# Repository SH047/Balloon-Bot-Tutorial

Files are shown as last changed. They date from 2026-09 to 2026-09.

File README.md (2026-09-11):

# Balloon Bot

Bluetooth gamepad-controlled robot built with an ESP32, Bluepad32, an L298N dual H-bridge motor driver, and two DC drive motors.

This repository includes two controller modes, mechanical CAD files, original tutorial and demonstration videos, and a wiring reference covering the requested 1000 µF capacitor and independent 18650-powered auxiliary motor.

## Wiring diagram

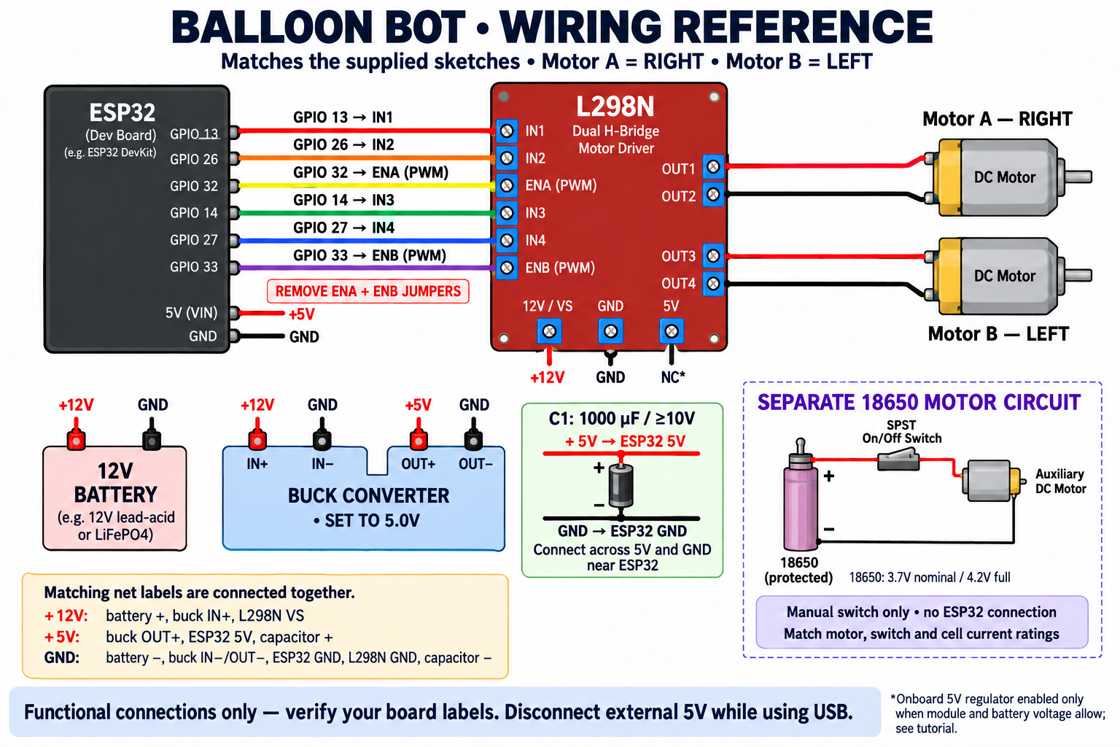
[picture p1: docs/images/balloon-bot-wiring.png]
Balloon Bot ESP32 and L298N wiring diagram


> [!IMPORTANT]
> The diagram and table follow the supplied sketches: **Motor A is the right motor** and **Motor B is the left motor**. Check the labels printed on your own ESP32 and L298N boards before applying power.

## ESP32 to L298N connections

| ESP32 pin | L298N pin | Function |
| --- | --- | --- |
| GPIO 13 | IN1 | Right motor direction 1 |
| GPIO 26 | IN2 | Right motor direction 2 |
| GPIO 32 | ENA | Right motor PWM / speed control |
| GPIO 14 | IN3 | Left motor direction 1 |
| GPIO 27 | IN4 | Left motor direction 2 |
| GPIO 33 | ENB | Left motor PWM / speed control |

Remove the black jumper caps from **ENA** and **ENB** before connecting GPIO 32 and GPIO 33. These enable pins receive PWM from the ESP32.

### Drive motors

- L298N `OUT1` and `OUT2` → right drive motor (Motor A)
- L298N `OUT3` and `OUT4` → left drive motor (Motor B)
- If a wheel turns in the wrong direction, disconnect power and swap that motor's two output wires.

## Main power wiring

Make every connection with the battery and USB cable disconnected.

| Source | Destination |
| --- | --- |
| 12V battery positive | L298N `12V / VS` and buck converter `IN+` |
| 12V battery negative | L298N `GND` and buck converter `IN−` |
| Buck converter `OUT+` set to 5.0V | ESP32 `5V / VIN` input, if supported by your board |
| Buck converter `OUT−` | ESP32 `GND` |
| ESP32 `GND` | L298N `GND` common ground |

The ESP32, L298N, buck converter, and main battery must share a common ground. Set and measure the buck converter output at **5.0V before connecting the ESP32**. Never connect the 12V battery directly to an ESP32 power pin, and never connect 5V to the ESP32 `3V3` pin.

The diagram leaves the L298N `5V` terminal disconnected. This assumes the module's separate `5V-EN` regulator jumper is fitted and the onboard regulator is compatible with the battery's fully charged voltage. L298N modules vary, so verify your module. Do not connect an enabled onboard 5V regulator output to the buck converter output.

## 1000 µF capacitor

Install a polarized **1000 µF electrolytic capacitor rated for 10V or higher** close to the ESP32:

```text
Buck OUT+ (5.0V) ────────┬──────── ESP32 5V
                         │ +
                    1000 µF
                     ≥ 10V
                         │ −
Buck OUT− (GND) ─────────┴──────── ESP32 GND
```

- Capacitor positive (`+`) → 5V
- Capacitor negative (`−`, normally marked with a stripe) → GND
- Connect it **in parallel across 5V and GND**, never in series.
- Keep the capacitor leads short.

## Separate 18650 motor circuit

The auxiliary motor is a separate manual circuit and has no connection to the ESP32 or L298N:

```text
Protected 18650 (+) ─── SPST on/off switch ─── Auxiliary motor (+)
Protected 18650 (−) ───────────────────────── Auxiliary motor (−)
```

Use a motor rated for a Li-ion cell's **3.7V nominal / 4.2V fully charged** voltage. The protected cell, holder, switch, and wiring must safely carry the motor's starting and stall current. Charge the cell only with a suitable Li-ion charger.

## Controller modes

### Single-stick arcade control

[SingleStickctrl.ino](SingleStickctrl/SingleStickctrl.ino) uses the left stick for throttle and steering, mixing both values into left- and right-wheel commands.

### Two-stick tank control

[TankdrvCtrl.ino](TankdrvCtrl/TankdrvCtrl.ino) uses the right stick for Motor A/right and the left stick for Motor B/left.

Both sketches use a deadzone and capped PWM output. Read the documented [failsafe limitation](docs/TUTORIAL.md#code-behavior-and-limitation) before testing.

## Arduino setup

1. Install [Arduino IDE](https://www.arduino.cc/en/software).
2. Follow the [Bluepad32 Arduino setup guide](https://bluepad32.readthedocs.io/en/latest/plat_arduino/).
3. Install the ESP32 and ESP32 + Bluepad32 board packages.
4. Select your compatible original ESP32 board under **Tools → Board → ESP32 + Bluepad32 Arduino**.
5. Open one controller sketch, select the USB port, and upload it.
6. Open Serial Monitor at **115200 baud** and pair the controller.

For PS4/PS5-style controllers that use Bluetooth Classic, use an original ESP32 such as an ESP32-WROOM-32 board. ESP32-S3 and ESP32-C3 boards do not provide Bluetooth Classic.

## Videos

- [Code training tutorial](videos/Ballon%20bot%20Code%20training%20.mov)
- [Balloon Bot demonstration](videos/Demo%20Ballon%20bot%20.mp4)
- [Download both original recordings from the GitHub release](https://github.com/SH047/Balloon-Bot-Tutorial/releases/tag/videos-v1)

## Repository contents

```text
Balloon-Bot-Tutorial/
├── SingleStickctrl/       Single-stick arcade control sketch
├── TankdrvCtrl/           Two-stick tank control sketch
├── Ballon BotCAD /        STL and DXF mechanical parts
├── docs/                  Full tutorial, validation, and wiring assets
├── videos/                Original tutorial and demonstration recordings
└── README.md              Project overview and wiring guide
```

## Documentation

Both sketches compile successfully against the ESP32 + Bluepad32 board package. See [VALIDATION.md](docs/VALIDATION.md) for recorded checks and [TUTORIAL.md](docs/TUTORIAL.md) for detailed assembly, testing, troubleshooting, and safety notes.

## Author

Created by [Shreyas S Rai](https://github.com/SH047).

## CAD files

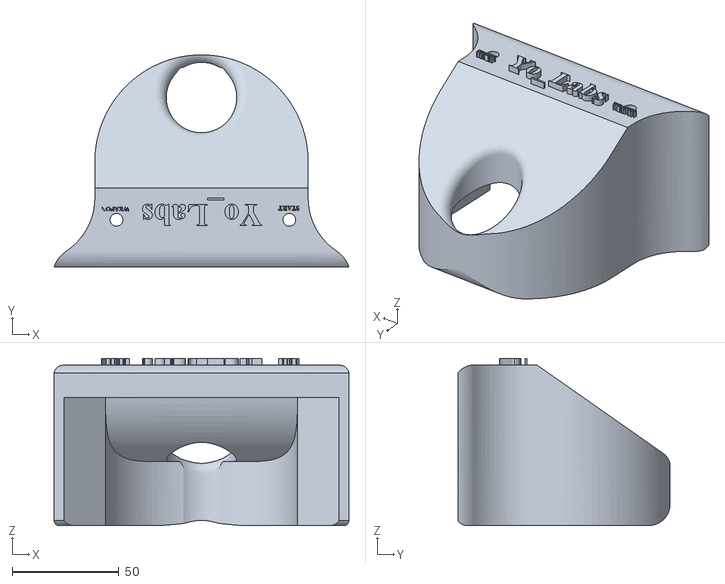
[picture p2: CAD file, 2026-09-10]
Ballon BotCAD /RED Ballon Front.stl
138.3 x 99.5 x 78.3

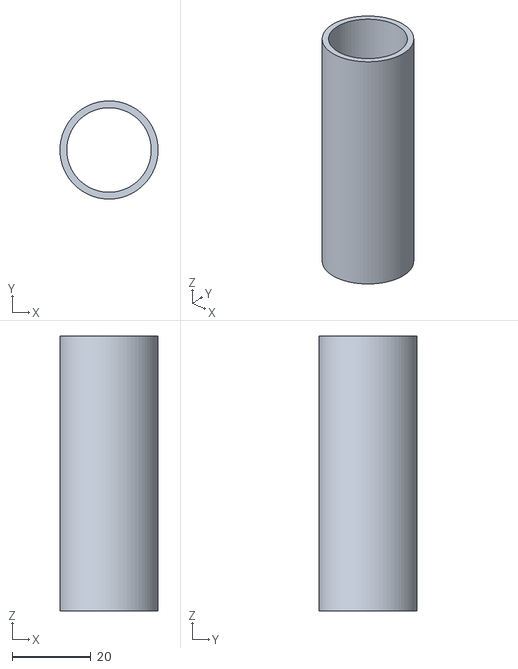
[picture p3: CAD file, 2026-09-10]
Ballon BotCAD /pvc 70 mm.stl
25.0 x 25.0 x 70.0

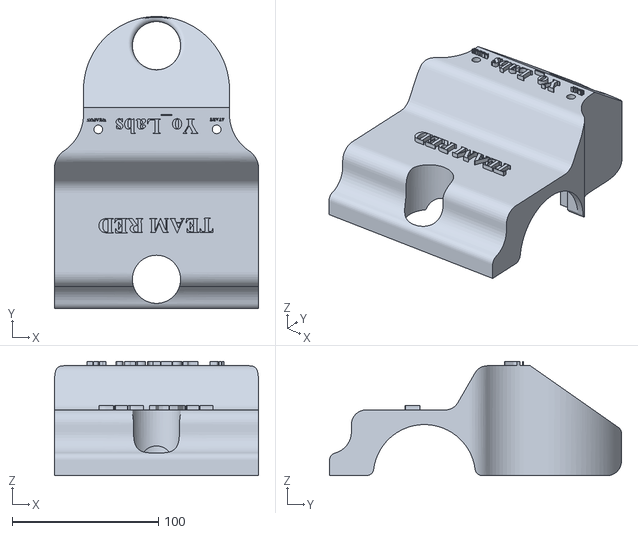
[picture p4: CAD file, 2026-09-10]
Ballon BotCAD /RED TEam Ballon.stl
140.0 x 200.0 x 78.3

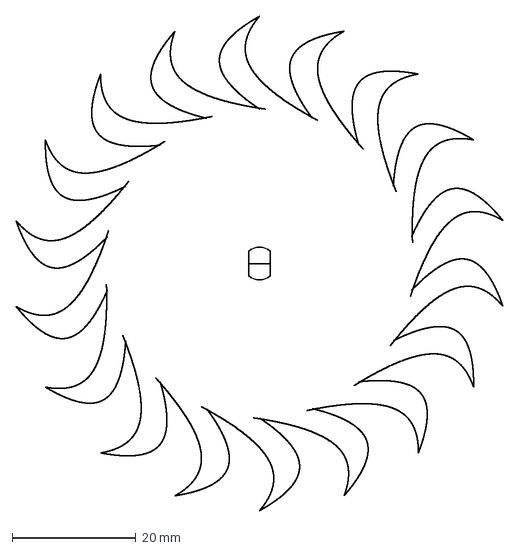
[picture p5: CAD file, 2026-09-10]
Ballon BotCAD /Spin blade V2 Harvest.dxf
78.8 x 80.0 mm

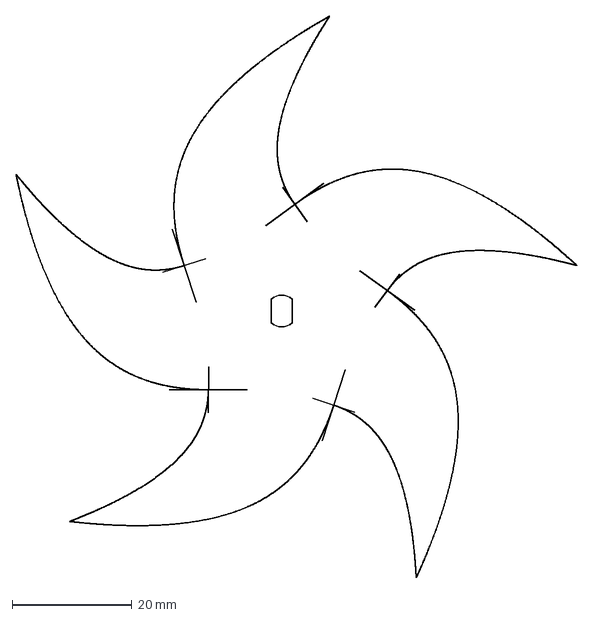
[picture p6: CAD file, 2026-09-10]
Ballon BotCAD /Saw2.dxf
93.9 x 94.0 mm

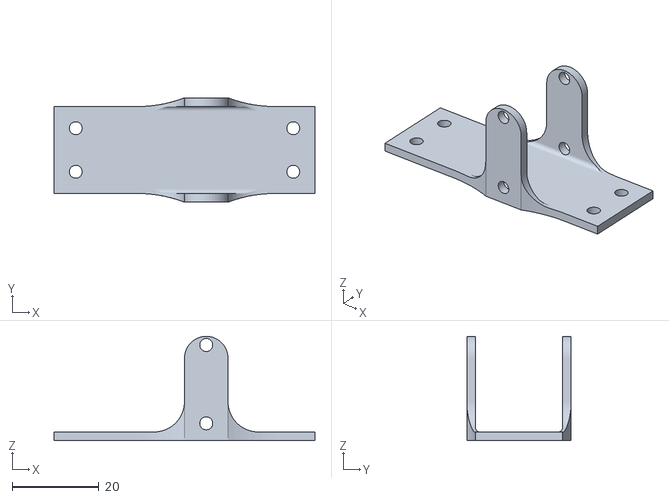
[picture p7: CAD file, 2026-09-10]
Ballon BotCAD /Bo motor mount.stl
60.0 x 24.0 x 24.0

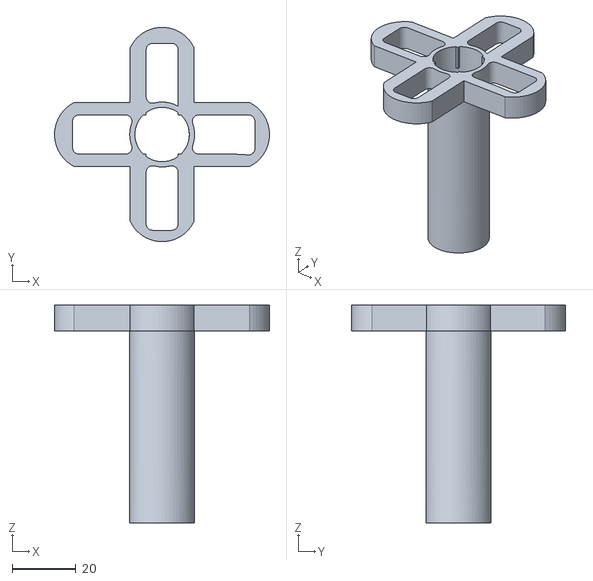
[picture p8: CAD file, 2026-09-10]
Ballon BotCAD /baloon holder.stl
67.2 x 67.0 x 68.0

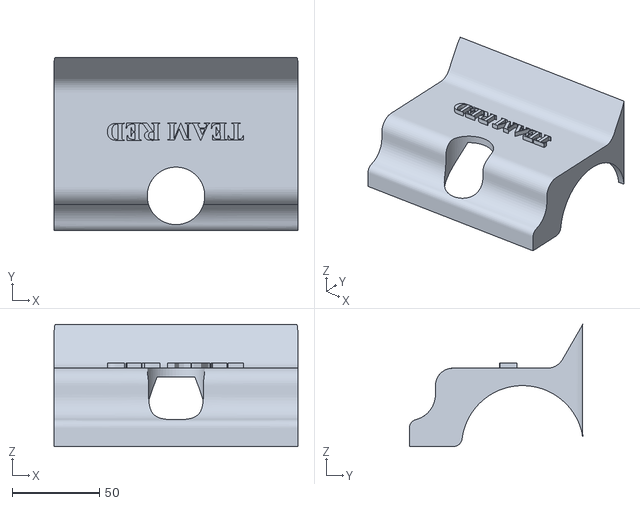
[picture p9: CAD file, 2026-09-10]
Ballon BotCAD /back red shell Baloon.stl
140.0 x 99.5 x 70.1

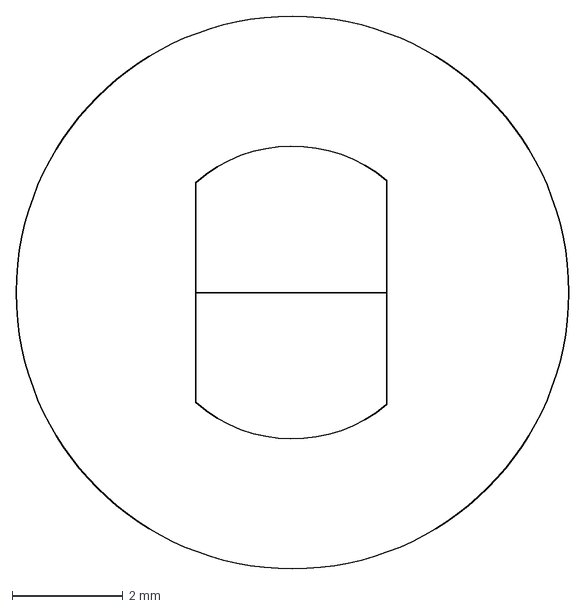
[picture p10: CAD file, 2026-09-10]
Ballon BotCAD /saw coupler.dxf
10.0 x 10.0 mm

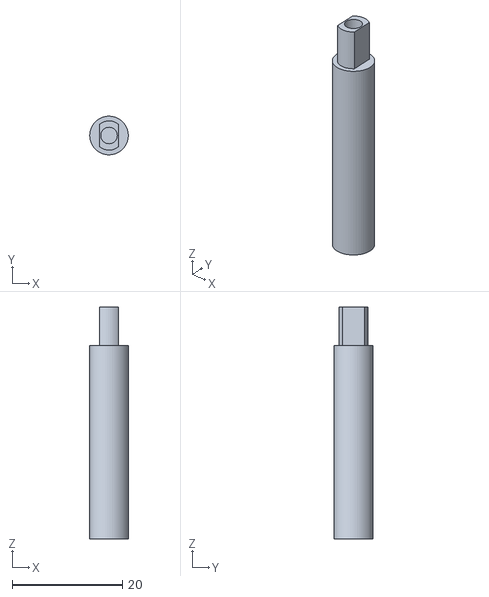
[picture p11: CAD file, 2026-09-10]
Ballon BotCAD /wepon coupler.stl
6.99 x 7.00 x 42.0

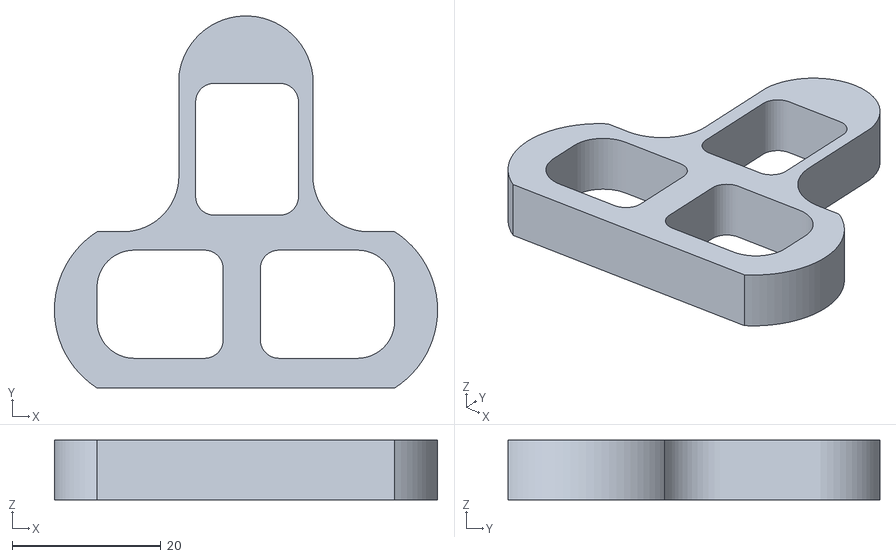
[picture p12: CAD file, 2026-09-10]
Ballon BotCAD /Ballon holder v1.stl
51.5 x 50.0 x 8.00

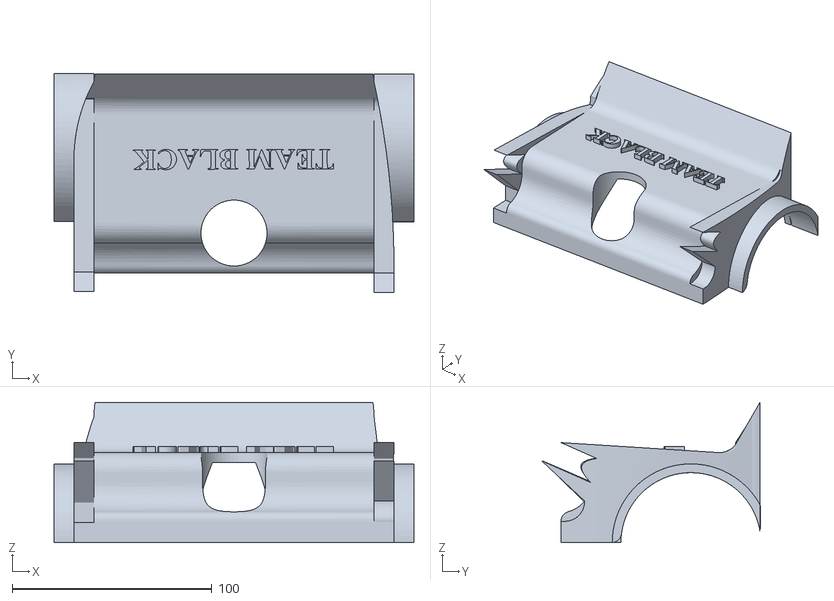
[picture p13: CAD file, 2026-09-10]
Ballon BotCAD / Blackshell Ballon back.stl
180.0 x 109.5 x 70.1

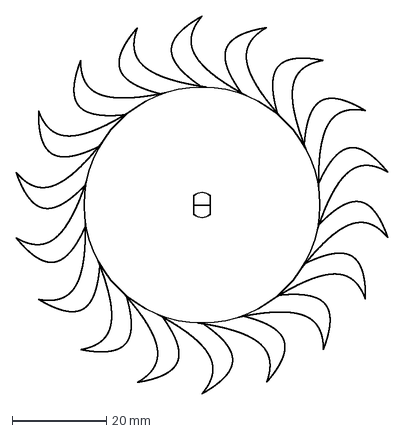
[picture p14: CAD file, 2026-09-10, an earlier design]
Ballon BotCAD /Spin blade V1 Harvest.dxf
78.8 x 80.0 mm

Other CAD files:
Ballon BotCAD /Front shell.stl

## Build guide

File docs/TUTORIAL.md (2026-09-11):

# ESP32 Balloon Bot: wiring and setup

This written companion follows the two original sketches and the [code-training recording](../videos/Ballon%20bot%20Code%20training%20.mov). It adds the requested 1000 µF capacitor and a separate, manually switched 18650 motor circuit.

## 1. Parts

- An original ESP32 development board with Bluetooth Classic, such as an ESP32-WROOM-32 DevKit, and a USB data cable.
- A compatible Bluetooth gamepad; the sketches print a PS5-controller connection message.
- An L298N dual H-bridge module and two drive motors compatible with the supply and driver.
- A suitable nominal 12V battery, wiring, connectors, and overcurrent protection sized for the motors and wiring.
- A buck converter that accepts the battery's **fully charged** voltage and provides regulated 5V with enough current for the ESP32.
- One polarized **1000 µF / 10V or higher** electrolytic capacitor.
- For the independent motor: one protected 18650 Li-ion cell in a holder, a DC-rated on/off switch, and a motor compatible with 3.7V nominal / 4.2V fully charged operation.
- Mechanical parts from the [CAD directory](../Ballon%20BotCAD%20/).

For a DualSense/PS5 controller, use an original ESP32 with Bluetooth Classic. ESP32-S3 and ESP32-C3 do not provide the required Classic transport. See the [Bluepad32 compatibility FAQ](https://bluepad32.readthedocs.io/en/latest/FAQ/).

## 2. Wiring reference

Complete Balloon Bot wiring reference

This is a **functional connection diagram**, not the physical header layout of a particular ESP32 or L298N board. Find the printed pin labels on your hardware. Matching net labels in the main power section mean those points must be wired together; the labels do not imply wireless connections.

### ESP32 to L298N

Both sketches declare the same six pins. Their motor-control calls assign **A to the right wheel and B to the left wheel**, correcting the opposite wheel labels in the original written notes.

| ESP32 pin | L298N pin | Function in the supplied code |
| --- | --- | --- |
| GPIO 13 | IN1 | Motor A — right, direction input 1 |
| GPIO 26 | IN2 | Motor A — right, direction input 2 |
| GPIO 32 | ENA | Motor A — right, PWM / speed |
| GPIO 14 | IN3 | Motor B — left, direction input 1 |
| GPIO 27 | IN4 | Motor B — left, direction input 2 |
| GPIO 33 | ENB | Motor B — left, PWM / speed |

Remove the black jumper caps from **ENA and ENB**, then connect GPIO 32 and GPIO 33 to the corresponding enable input pins. Do not connect them to the adjacent 5V jumper posts.

| L298N output | Motor connection |
| --- | --- |
| OUT1 and OUT2 | The two terminals of Motor A, the **right** drive motor |
| OUT3 and OUT4 | The two terminals of Motor B, the **left** drive motor |

If a wheel rotates opposite to the intended direction, turn power off and swap that motor's two output wires. Keep the A/right and B/left channels consistent with the sketches. The tank and arcade sketches handle Y-axis signs differently, so check direction whenever switching sketches.

## 3. Main battery, buck converter, and common ground

Make all connections with the battery and USB disconnected.

| From | To |
| --- | --- |
| Main battery positive | L298N `12V` / `VS` terminal and buck `IN+` |
| Main battery negative | L298N `GND` and buck `IN−` |
| Buck `OUT+`, adjusted to 5.0V | ESP32 board's documented **5V power input** |
| Buck `OUT−` | ESP32 `GND` and the main common ground |
| ESP32 `GND` | L298N `GND` |

The main common ground includes battery negative, L298N GND, buck IN−/OUT−, and ESP32 GND. This guide assumes a typical non-isolated buck converter. Verify your converter's terminal markings. Route motor-current returns directly to the supply/driver connection instead of through an ESP32 jumper wire.

Measure the buck output before attaching the ESP32. **Never apply 12V to the ESP32 5V pin, or 5V to its 3V3 pin.** A pin marked VIN is usable only if your development board documents it as the appropriate 5V input. Disconnect the external 5V supply before powering the board over USB, following the [Espressif DevKitC power guide](https://documentation.espressif.com/api/resource/path/docs/projects/esp-dev-kits/en/latest/esp32/esp32-devkitc/user_guide.html).

### L298N 5V terminal and regulator jumper

The drawing leaves the L298N **5V terminal disconnected** from the buck and ESP32. This assumes the module's onboard regulator supplies its logic power with the separate **5V-EN regulator jumper fitted**.

Confirm the module's allowed regulator-input range against the actual battery voltage, including fully charged voltage. A nominal 12V battery can exceed 12V when charged; the label alone does not establish compatibility. L298N boards vary. The [Handson Technology module guide](https://handsontec.com/dataspecs/module/L298N%20Motor%20Driver.pdf) illustrates the onboard regulator, its jumper, and external-5V operation.

If your module requires external logic power at the chosen battery voltage, remove its **5V-EN regulator jumper** and provide regulated 5V to its logic terminal according to that module's documentation. That is an alternative to the diagram's disconnected-5V arrangement. Do not join an enabled regulator's 5V output to the buck output. In either configuration, the **ENA and ENB PWM jumpers remain removed**.

### Add the 1000 µF capacitor

Connect C1 **in parallel across the buck's 5V output**, physically close to the ESP32 power pins:

```text
Buck OUT+ (5.0V) ────────┬──────── ESP32 5V
                        │ +
                   C1 1000 µF
                      ≥ 10V
                        │ −
Buck OUT− (GND) ────────┴──────── ESP32 GND
```

The capacitor's positive lead goes to 5V; its negative lead (usually identified by the stripe) goes to GND. Keep both leads short. Do not put the capacitor in series with the ESP32 supply. If adding another 1000 µF capacitor, connect it across the same rails with the same polarity and confirm that the buck supports the total output capacitance. Bulk capacitance can help with brief supply dips, but does not replace adequate supply current and good wiring.

## 4. Separate 18650 → switch → motor

The boxed auxiliary circuit is independent of the ESP32 and L298N:

```text
Protected 18650 (+) ─── SPST on/off switch ─── Motor (+)
Protected 18650 (−) ───────────────────────── Motor (−)
```

Use a motor rated for the cell's 4.2V full-charge voltage, and a cell, protection circuit, switch, and wires that can handle its starting/stall current. Use a suitable holder and charger for the cell. This motor is operated by the physical switch only; the supplied sketches cannot start or stop it. No common-ground connection to the main robot circuit is needed for this independent loop. Keep it switched off during drive-system setup.

## 5. Upload one sketch

Install the ESP32 and ESP32 + Bluepad32 board packages using the [official Bluepad32 Arduino setup guide](https://bluepad32.readthedocs.io/en/latest/plat_arduino/). In Arduino IDE's Additional Boards Manager URLs, add:

```text
https://raw.githubusercontent.com/espressif/arduino-esp32/gh-pages/package_esp32_index.json
https://raw.githubusercontent.com/ricardoquesada/esp32-arduino-lib-builder/master/bluepad32_files/package_esp32_bluepad32_index.json
```

Select your board under **Tools → Board → ESP32 + Bluepad32 Arduino**, then select its USB port. Open and upload **one** of these:

- [SingleStickctrl.ino](../SingleStickctrl/SingleStickctrl.ino): left stick provides throttle and steering. The code negates Y for throttle, then computes `leftPower = throttle + turn` and `rightPower = throttle - turn`.
- [TankdrvCtrl.ino](../TankdrvCtrl/TankdrvCtrl.ino): right-stick Y controls Motor A/right; left-stick Y controls Motor B/left. This sketch passes the raw Y-axis signs to the motor function.

Keep each sketch in its matching folder. Do not combine them into one Arduino sketch. Open Serial Monitor at **115200 baud**, put the controller into its documented Bluetooth pairing mode, and watch for the connection callback. Use the controller manufacturer's pairing instructions for your model.

## 6. Test the controls

1. Keep wheels clear of the ground and the separate auxiliary motor off.
2. Check polarity, grounds, the 5V measurement, capacitor orientation, and all three L298N jumper settings.
3. Power the main circuit, pair the controller, and move the sticks gently.
4. Confirm the right and left channels, then check forward/reverse and steering. Remove power before changing motor wires.
5. Release the sticks and verify that both wheel motors stop.
6. Turn off the controller and verify disconnect stopping. Test with an accessible physical power cutoff.
7. Test the independent 18650 motor separately with its own switch.

The code uses `DEADZONE = 15`, `MIN_PWM = 60`, and `MAX_PWM = 120`; motor commands are constrained to −512…512. PWM limits do not guarantee safe stall current, motor voltage, or driver temperature. Avoid sustained stalls and check the hardware ratings.

### Code behavior and limitation

Both sketches stop the motors at startup, inside the deadzone, and in the controller-disconnect callback. They declare `COMMAND_TIMEOUT = 300`, but update `lastCommandTime` on every loop that finds a connected controller, without checking whether a **new input packet** arrived. Consequently, the timeout is not a reliable stale-packet failsafe while the controller remains marked connected. The sketches also process only `myControllers[0]`.

These original sketches are retained unchanged for reference. A future failsafe improvement should update the command timestamp only when fresh, valid gamepad data arrives and be verified with packet-loss and disconnect tests. Treat the physical power cutoff as necessary during initial testing.

## Troubleshooting

| Symptom | Check |
| --- | --- |
| `Bluepad32.h` is missing | Use the ESP32 + Bluepad32 board package and board selection |
| PS5 controller will not pair | Original ESP32 / Bluetooth Classic support and controller pairing mode |
| Motors run at fixed speed | ENA/ENB jumpers removed; GPIO 32/33 on the enable inputs |
| Left/right controls are reversed | OUT1/2 = right; OUT3/4 = left, matching the code |
| A motor rotates backward | With power off, reverse that motor's two wires |
| ESP32 resets as motors start | Buck current capability, 5V wiring, common-ground routing, and C1 polarity/placement |
| L298N is powered but unresponsive | Logic 5V supply/regulator configuration and common ground |
| Auxiliary motor ignores the gamepad | Expected: it is controlled only by its separate switch |

## Image and verification notes

The PNG was created and corrected with the built-in image-generation tool. The [initial prompt](images/wiring-image-prompt.txt) and [final correction prompt](images/wiring-image-edit-prompt.txt) are included for reproducibility. The signal labels and wheel assignments were checked against both sketches. The final power connections use explicit net labels to avoid ambiguous crossings.

Documentation review does not establish that the physical hardware has been tested. Verify your actual board variant, battery, converter, capacitor, and motor ratings before assembly.

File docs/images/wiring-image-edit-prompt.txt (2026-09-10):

Edit this wiring reference. Keep the upper six GPIO connections, L298N motor output connections, both wheel motor labels, title and the entire isolated 18650 panel unchanged. COMPLETELY REPLACE THE MAIN POWER-WIRING AREA with a clean net-label schematic to eliminate ALL wrong crossed/shorted connections. Do not run any long wires in the power section.
Specifically erase EVERY existing wire below the six GPIO wires connecting ESP32 power, L298N power, battery, buck and capacitor. Erase old battery and buck art and redraw as simple clean labeled rectangles.
Use short isolated labeled terminal stubs, with IDENTICAL NET LABELS meaning electrical connection. Three nets ONLY: +12V, +5V, GND. +12V and +5V and GND NEVER joined.
ESP32 5V terminal: short red stub left or right with label "+5V". ESP32 GND terminal: short black stub with label "GND".
L298N 12V / VS terminal: short red downward stub labeled "+12V". L298N GND terminal: short black downward stub labeled "GND". L298N 5V terminal: no connection, label "NC*".
Power panel below: battery rectangle with + terminal stub labeled "+12V" and − terminal stub labeled "GND". Explicitly BOTH stubs connect to their respective terminals.
Buck rectangle: "BUCK • SET TO 5.0V". Four short stubs: IN+ labeled "+12V"; IN− labeled "GND"; OUT+ labeled "+5V"; OUT− labeled "GND".
Capacitor inset: two parallel horizontal rails. Upper red rail labeled "+5V → ESP32 5V", lower black rail labeled "GND → ESP32 GND". One vertical polarized capacitor C1 bridges the rails, upper lead +, lower lead −. Label "1000 µF / ≥10V". Caption "Connect across 5V and GND near ESP32".
Power panel explanatory legend: "Matching net labels are connected together." "+12V: battery +, buck IN+, L298N VS" "+5V: buck OUT+, ESP32 5V, capacitor +" "GND: battery −, buck IN−/OUT−, ESP32 GND, L298N GND, capacitor −". Draw NO extra connecting wires between blocks; ONLY terminal stubs and these clear matching net labels. No short circuits, no mixing +12V and +5V. Preserve footer note about onboard regulator and USB. Image should be clean and all text legible.

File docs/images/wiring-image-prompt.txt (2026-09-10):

Use case: scientific-educational
Asset type: GitHub tutorial wiring reference, landscape high-resolution infographic.
Title: "BALLOON BOT • WIRING REFERENCE"
Create an accurate, clean engineering wiring illustration using simplified labeled module blocks, tidy right-angle wires, white background, large legible typography. This is a functional schematic, not a physical board pin-position map. Put this subtitle: "Matches the supplied sketches • Motor A = RIGHT • Motor B = LEFT".
Upper half: ESP32 block at left and L298N block at center, two DC motors at right. Six separate horizontal color-coded wires with endpoints explicitly labeled exactly:
GPIO 13 → IN1
GPIO 26 → IN2
GPIO 32 → ENA (PWM)
GPIO 14 → IN3
GPIO 27 → IN4
GPIO 33 → ENB (PWM)
L298N OUT1 and OUT2 each connect to one terminal of Motor A — RIGHT.
L298N OUT3 and OUT4 each connect to one terminal of Motor B — LEFT.
Callout by ENA/ENB: "REMOVE ENA + ENB JUMPERS".
Lower-left power section: one 12V battery with + and − terminals; battery + branches to L298N 12V / VS and buck IN+. Battery − joins common ground, L298N GND and buck IN−. Buck block reads "BUCK CONVERTER • SET TO 5.0V". Buck OUT+ connects directly to ESP32 5V input (never 3V3); buck OUT− connects ESP32 GND and the common ground. Clearly draw one polarized electrolytic capacitor C1 as a branch ACROSS the +5V and GND rails near ESP32, with "+" marked on its +5V terminal and "−" on GND terminal. Label "C1 1000 µF / 10V or higher" and "Parallel across 5V and GND • close to ESP32". Capacitor is NOT in series. Red +5V wire remains continuous to ESP32. Black common-ground wire remains continuous. Use explicit net labels if needed to avoid crossing.
L298N 5V terminal ends unconnected, labeled "5V: NO CONNECTION*". Footnote: "*Onboard 5V regulator enabled only when module and battery voltage allow; see tutorial."
Lower-right clearly boxed electrically isolated circuit: "SEPARATE 18650 MOTOR CIRCUIT". One protected 18650 cell symbol, "+" connects to an SPST on/off switch, then auxiliary DC motor positive; motor negative returns to cell "−" in a complete loop. Text: "18650: 3.7V nominal / 4.2V full". "Manual switch only • no ESP32 connection". No wires or ground symbols connecting this circuit to main circuit. Use a motor rated for this voltage. Add label "Match motor, switch and cell current ratings".
Footer: "Functional connections only — verify your board labels. Disconnect external 5V while using USB."
Critical: include all six correct GPIO pairs; all motor terminals connected; show capacitor polarity and parallel branch unambiguously; keep auxiliary battery isolated; no decorative extra wires.

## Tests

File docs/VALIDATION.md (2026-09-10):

# Validation record

Checked on 2026-09-10 using the locally installed Arduino CLI and ESP32 + Bluepad32 4.1.0 board package.

## Compilation

Board target: `esp32-bluepad32:esp32:esp32` (generic original ESP32).

| Sketch | Result | Flash usage | Global RAM usage |
| --- | --- | --- | --- |
| `SingleStickctrl/SingleStickctrl.ino` | Passed | 719,033 bytes / 1,310,720 | 87,212 bytes / 327,680 |
| `TankdrvCtrl/TankdrvCtrl.ino` | Passed | 719,005 bytes / 1,310,720 | 87,212 bytes / 327,680 |

Commands, run from the repository root:

```sh
arduino-cli compile --fqbn esp32-bluepad32:esp32:esp32 SingleStickctrl
arduino-cli compile --fqbn esp32-bluepad32:esp32:esp32 TankdrvCtrl
```

## Documentation checks

- Verified all six GPIO constants in both sketches against the tutorial.
- Verified A/right and B/left using each sketch's motor-control calls.
- Confirmed the sketch copies in the CAD folder match the root sketch files byte-for-byte.
- Verified relative file links in the README and tutorial resolve locally.
- Visually reviewed the final generated image: six GPIO pairs, both motor output pairs, three distinct main power nets, capacitor polarity and parallel connection, and the isolated switched 18650 loop.
- Kept original code, videos, and CAD files unchanged. Original sketch whitespace and CAD formatting are preserved.

Compilation does not verify physical wiring, motor direction, thermal performance, controller pairing, or failsafe behavior. No board was flashed and no hardware test was performed in this session. The stale-packet timeout limitation is documented in the tutorial.

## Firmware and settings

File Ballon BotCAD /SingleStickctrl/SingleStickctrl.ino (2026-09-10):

#include <Bluepad32.h>
#include "esp_system.h"

// Motor A (Right Motor)
const int IN1 = 13;
const int IN2 = 26; 
const int ENA = 32; 

// Motor B (Left Motor)
const int IN3 = 14;
const int IN4 = 27;
const int ENB = 33; 

const int DEADZONE = 15;
const int MIN_PWM = 60;  
const int MAX_PWM = 120; 

unsigned long lastCommandTime = 0;
const unsigned long COMMAND_TIMEOUT = 300; 

ControllerPtr myControllers[BP32_MAX_GAMEPADS];

void setup() {
  Serial.begin(115200);
  
  Serial.println("\n=======================================================");
  Serial.printf("ESP32 BOOTED. Reset reason: %d\n", esp_reset_reason());
  Serial.println("=======================================================\n");

  pinMode(IN1, OUTPUT);
  pinMode(IN2, OUTPUT);
  pinMode(ENA, OUTPUT);
  
  pinMode(IN3, OUTPUT);
  pinMode(IN4, OUTPUT);
  pinMode(ENB, OUTPUT);
  
  stopMotors();

  BP32.setup(&onConnectedController, &onDisconnectedController);
  
  Serial.println("System ready. Waiting for PS5 Controller...");
}

void loop() {
  BP32.update();
  processController();

  if (millis() - lastCommandTime > COMMAND_TIMEOUT) {
    stopMotors();
  }

  delay(5);
}

void onConnectedController(ControllerPtr ctl) {
  for (int i = 0; i < BP32_MAX_GAMEPADS; i++) {
    if (myControllers[i] == nullptr) {
      Serial.printf("CALLBACK: Controller connected, index=%d\n", i);
      myControllers[i] = ctl;
      break;
    }
  }
}

void onDisconnectedController(ControllerPtr ctl) {
  for (int i = 0; i < BP32_MAX_GAMEPADS; i++) {
    if (myControllers[i] == ctl) {
      Serial.printf("CALLBACK: Controller disconnected, index=%d\n", i);
      myControllers[i] = nullptr;
      stopMotors();
      break;
    }
  }
}

void setMotor(int in1, int in2, int en, int value) {
  value = constrain(value, -512, 512);

  if (abs(value) <= DEADZONE) {
    digitalWrite(in1, LOW);
    digitalWrite(in2, LOW);
    analogWrite(en, 0);
    return;
  }

  int pwm = map(abs(value), DEADZONE, 512, MIN_PWM, MAX_PWM);
  pwm = constrain(pwm, MIN_PWM, MAX_PWM);

  if (value > 0) {
    digitalWrite(in1, HIGH);
    digitalWrite(in2, LOW);
  } else {
    digitalWrite(in1, LOW);
    digitalWrite(in2, HIGH);
  }

  analogWrite(en, pwm);
}

void processController() {
  ControllerPtr ctl = myControllers[0];
  
  if (!ctl || !ctl->isConnected()) {
    return; 
  }

  // Bluepad32 Y-axis is negative when pushed up. Invert it so forward is positive.
  int throttle = -constrain(ctl->axisY(), -512, 512);
  // X-axis is negative for left, positive for right.
  int turn = constrain(ctl->axisX(), -512, 512);

  // Arcade drive mixing
  int leftPower = throttle + turn;
  int rightPower = throttle - turn;

  // Re-constrain mixed values to the expected -512 to 512 range
  leftPower = constrain(leftPower, -512, 512);
  rightPower = constrain(rightPower, -512, 512);

  lastCommandTime = millis();

  // Send mapped power to corresponding motors
  setMotor(IN3, IN4, ENB, leftPower);  // Motor B (Left)
  setMotor(IN1, IN2, ENA, rightPower); // Motor A (Right)
}

void stopMotors() {
  digitalWrite(IN1, LOW);
  digitalWrite(IN2, LOW);
  analogWrite(ENA, 0);
  
  digitalWrite(IN3, LOW);
  digitalWrite(IN4, LOW);
  analogWrite(ENB, 0);
}
